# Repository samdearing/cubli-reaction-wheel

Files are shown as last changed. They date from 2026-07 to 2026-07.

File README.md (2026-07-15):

# Cubli — a 3-axis reaction-wheel balancing cube

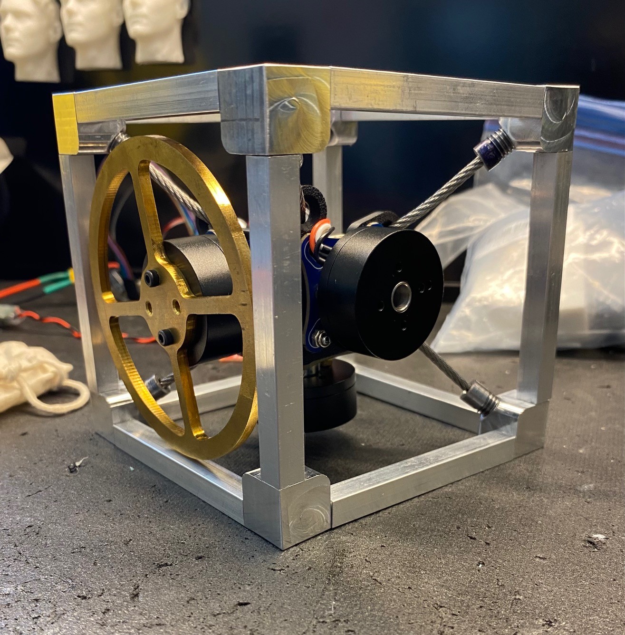
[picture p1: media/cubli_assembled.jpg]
Cubli reaction-wheel cube — first trial assembly


*First trial fit-up — dry-assembled to check clearances and see how the parts come together.
Not the finished build; frame tensioning, wiring, and final balancing are still in progress.*

A cube that balances on its corner using three orthogonal reaction wheels. Built as
phase one of a two-project arc: the ADCS stack developed here — IMU drivers, quaternion
attitude estimation, nested control loops, BLDC torque control — ports directly to an
active thrust-vector-controlled model rocket.

**Status:** prototype assembled; single-axis controller validated in simulation; **motor
bring-up complete** — one axis spinning under SimpleFOC with the encoder confirming
commanded velocity. Closed-loop edge balance is the next milestone.

---

## Why this project

Reaction-wheel attitude control is the same problem a CubeSat solves in orbit, reduced to
something you can drop on a desk. The wheel saturation, the momentum budget, the sensor
fusion, the torque-vs-momentum trade — all of it is spacecraft ADCS with gravity added as a
disturbance you can't turn off.

I built it to *understand* those things, not to reproduce a demo. Where a decision could
have been hand-waved, the reasoning is written down.

---

## The engineering, in three decisions

**The wheel is torque-limited, not momentum-limited — so bigger isn't better.**
The obvious instinct is to add wheel inertia for more authority. It's wrong. Extra rim mass
raises the gravity torque the wheel has to fight (`mgl`) faster than it raises the momentum
ceiling, and the recovery envelope is bounded by the motor's 0.087 N·m peak, not by stored
momentum. Simulation puts peak wheel speed at 56 % of the flat-torque knee during a worst-case
catch — enormous saturation margin, which is the signature of a torque-bound system. The
inertia target sits at **8.00e-5 kg·m² reflected**: the broad envelope optimum is ~7.5e-5, and
8e-5 is *also* the floor for a multi-swing pump-up hop, so one wheel design serves all three
phases instead of two. → [`docs/HARDWARE.md` §8](docs/HARDWARE.md)

**A sensor's I2C address propagated into the motor wiring harness.**
The AS5600 encoder has a hardwired address of `0x36` and no address pins — so three of them
cannot share a bus. That forces all three of the Teensy 4.1's native I2C peripherals into
service, which claims pins 24/25 for `Wire2`. Those pins happen to be FlexPWM1's sm2-X and
sm3-X outputs. FlexPWM1's usable PWM pool collapses to `{0, 1, 7, 8}`, FlexPWM3 only exposes
one submodule and can't drive a motor at all, and the whole motor pin allocation becomes
*forced* rather than chosen — including one unavoidable stray wire in the M3 harness bundle.
Traceable end to end from an encoder datasheet to a connector. → [`docs/HARDWARE.md` §11.3](docs/HARDWARE.md)

**The frame is a tensegrity, and seven stays is not a guess.**
The motor hub is a free rigid body — 6 DOF. Six cable stays can *locate* it but leave no state
of self-stress, so they'd only go taut under external load: useless as a preloaded mount. The
seventh adds exactly one self-stress state, and that self-stress *is* the preload (Maxwell:
members − 6 = self-stresses − mechanisms). The count is necessary but not sufficient — the
stays must also be arranged off the hub's center, or they lock the translations and leave it
free to spin. → [`docs/FRAME_BUILD_GUIDE.md` §2](docs/FRAME_BUILD_GUIDE.md)

---

## Architecture

Three nested loops:

| Loop | Runs at | Does |
|---|---|---|
| **Attitude** (outer) | 1 kHz | Estimated quaternion → commanded body-axis torques. PD + desaturation for single-axis; LQR for 3-axis. |
| **Allocation** (middle) | 1 kHz | Body-axis torques → per-wheel torques. Trivial for perfectly orthogonal wheels; not for real ones. |
| **Torque** (inner) | SimpleFOC | Per-motor voltage-mode torque with *estimated* current. |

**State estimation:** Madgwick → EKF. Madgwick first, deliberately, so the EKF is understood as
an answer to Madgwick's specific failures rather than adopted as a black box.

**Honest limitation:** the SimpleFOC Mini has no current-sense shunts, so the "current limit" is
enforced against an estimate derived from phase resistance — and copper resistance rises ~0.4 %/°C,
so a hot winding draws more than the estimate believes. A flight reaction-wheel driver carries a
true closed current loop for exactly this reason. Fine for low-duty balancing bursts; documented
rather than papered over.

---

## Hardware

| | |
|---|---|
| MCU | Teensy 4.1 (i.MX RT1062, 600 MHz M7 + FPU) — chosen for its **three native I2C buses** |
| Motors | QiuLovesYT 2804 BLDC ×3 — 220 KV, Kt = 0.0434 N·m/A, 7 pole pairs |
| Drivers | SimpleFOC Mini ×3 (DRV8313) — no current sense |
| Encoders | AS5600 ×3 — 12-bit magnetic, fixed 0x36 |
| IMU | SparkFun ISM330DHCX — raw 6-axis; fusion written from scratch |
| Wheels | CNC C360 brass, spoked, 87 mm OD, 65 g, 8.00e-5 kg·m² reflected |
| Frame | Pre-tensioned aluminum space-frame — 12-tube cage, machined hub, 7 cable stays |
| Power | 4S 650 mAh LiPo, star-ground distribution, 7.5 A fuse, XT30 loop key |

Full spec, wiring, pin map and limits: [`docs/HARDWARE.md`](docs/HARDWARE.md) — the single
source of truth.

---

## Simulation

Every design decision is traced through the sim before anything is cut or flashed.
*Tune in sim, then port* is the workflow, not a slogan.

```
sim/
  params.py       mass properties, motor constants, geometry
  plant.py        1-DOF rigid body + reaction wheel
  motor.py        torque envelope, saturation, back-EMF taper
  controller.py   PD + wheel desaturation
  run.py          disturbance-rejection cases, plots
```

**Validated result:** catches a 3° release + 1.0 rad/s shove down to 0.13° final tilt.
Max recoverable disturbance ≈ 1.6 rad/s (~93 °/s). Balance holds with stock gains across
±30 % on mass and inertia — the design is not gain-fragile.

Locked gains: `Kp 1.40, Kd 0.080, Kw +1e-4`. The sign on `Kw` is load-bearing — flipping it
places a right-half-plane pole and the wheel desaturates *into* the fall.

---

## Roadmap

- [x] Wheel inertia sized, balance confirmed in CAD, sim-validated
- [x] Battery + CM ballast plan closed
- [x] Electrical pin map derived and locked
- [ ] **Phase 1** — single-axis edge balance → *video of the cube balancing on an edge*
- [ ] **Phase 2** — 3-axis corner balance under LQR → *video with disturbance rejection*
- [ ] **Phase 3** — multi-swing pump-up onto a corner → *video of the hop*

---

## Repo layout

```
docs/     HARDWARE.md (source of truth) · FRAME_BUILD_GUIDE.md
          CUBLI_BUILD_CONSIDERATIONS.md · cubli_wiring_reference.html (harness ICD)
sim/      Python plant model, controller, disturbance studies
firmware/ Teensy 4.1 / SimpleFOC — bring-up + IMU sketches
cad/      SolidWorks — frame, hub, wheel, assemblies
```

---

Sam Dearing · B.S. Aerospace Engineering (astronautics), Arizona State University

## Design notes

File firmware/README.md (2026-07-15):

# Cubli — Firmware

Teensy 4.1 + SimpleFOC + AS5600. Arduino IDE 2.x.

## ⚠ REQUIRED: SimpleFOC library version 2.3.5

**Do not use SimpleFOC 2.4.0.** Its Teensy-4 driver is broken: `driver.init()` reports success
and configures the FlexPWM timers, but **no PWM ever reaches the pins** — 0 V output, motor dead,
no error. Diagnosed 2026-07-14 on this exact hardware by measuring: raw `analogWrite` on pins
4/5/6 worked perfectly, yet SimpleFOC 2.4.0 produced nothing. **2.3.5 fixes it instantly.**

Install: Arduino IDE → Library Manager → *Simple FOC* → version dropdown → **2.3.5**.

Center-aligned 3PWM is **not** used — it only matters for low-side current sensing, which the
SimpleFOC Mini doesn't have. Plain fast-pwm (the 2.3.5 default) is correct for voltage-mode
torque control. No `build_opt.h` flags, no library edits.

## Sketches

| Sketch | Purpose |
|---|---|
| **`m1_bringup/`** | The real bench tool. Serial-driven: I2C scan, encoder stream, open-loop M1 spin with encoder feedback, VBAT read, per-command enable/disable, safety timeouts. M2/M3 held disabled at the driver. **Start here.** |
| `m1_minimal/` | Barest SimpleFOC open-loop spin — no encoder, no serial. Used to isolate library vs sketch during debugging. |
| `diag_debug/` | SimpleFOC with `SimpleFOCDebug::enable()` — prints the library's PWM config decisions. The sketch that exposed the 2.4.0 bug. |
| `pwm_raw_test/` | Raw `analogWrite` on 4/5/6, no SimpleFOC. Proves the Teensy PWM hardware independent of the library. |
| `analogwrite_spin/` | Hand-rolled 3-phase sine open-loop spinner, no SimpleFOC. Proves the motor+driver turn independent of the library. |

The four small sketches are debugging artifacts kept deliberately — they're the isolation ladder
that located the 2.4.0 regression, and they'll re-diagnose any future "motor won't spin" problem.

## Pin map (Rev C — see `docs/HARDWARE.md` §11)

| Motor | IN1 | IN2 | IN3 | EN | Encoder bus |
|---|---|---|---|---|---|
| M1 | 4 | 5 | 6 | 3 | `Wire` (18/19) |
| M2 | 22 | 23 | 2 | 21 | `Wire1` (17/16) |
| M3 | 8 | 7 | 1 | 9 | `Wire2` (25/24) |

## Open-loop safety

`voltage_limit` is hard-capped at **3.0 V** in the bring-up sketch. Open loop has no back-EMF at
standstill and the Mini has no current shunts, so `I = U / Rs = U / 2.55 Ω`. The closed-loop
14.5 V would draw 5.7 A into a 2 A motor. Do not raise the open-loop cap. It returns to 14.5 V
only after `initFOC()` succeeds and the loop is closed.

## Status

- [x] I2C scan, encoder hand-turn, phase/continuity checks — all pass
- [x] M1 open-loop spin, encoder tracks commanded velocity (2026-07-14)
- [ ] `initFOC()` sensor alignment + closed-loop torque (resolves the open-loop sign flip)
- [ ] VBAT sense divider — **not yet built** (pin 41 currently floats; the ~6 V it reads is noise)

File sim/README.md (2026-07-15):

Python plant model, controller and disturbance studies.
Drop params.py / plant.py / motor.py / controller.py / run.py here.

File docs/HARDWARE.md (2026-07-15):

# Cubli — Hardware Specification (as purchased)

> **Source of truth.** This sheet reflects the parts actually bought and supersedes the
> hardware called out in the original project brief. Where it differs from the brief,
> *this document wins.* Substitutions vs. the brief are noted in the changelog at the bottom.
>
> **Rev C — 2026-07-14.** Electrical wiring, the Teensy pin map, VBAT sense, the BEC, and the
> connector ICD are now **locked in §11**. They previously lived only in conversation memory.

---

## 1. Microcontroller

| | |
|---|---|
| Board | **Teensy 4.1** |
| MCU | i.MX RT1062, 600 MHz Cortex-M7 + hardware FPU |
| Logic level | 3.3 V |
| I2C buses (exposed) | **3** — `Wire` (SDA 18 / SCL 19), `Wire1` (SDA 17 / SCL 16), `Wire2` (SDA 25 / SCL 24) |
| Power (bench) | **USB** (5 V → onboard 3.3 V regulator) |
| Power (untethered) | 3 A BEC → `VIN`, **after** the VUSB↔VIN pad cut — see §11.7 |

The three independent I2C buses are load-bearing for this design — see §6.

> `Wire2` (SDA 25 / SCL 24) has **no alternate pins** on this MCU. Those two pins are also
> FlexPWM1's sm2-X and sm3-X outputs, so committing to a third I2C bus removes them from the
> PWM pool. That is what forces the motor pin allocation in §11.3 — the constraint is real and
> traceable, not a layout accident.

---

## 2. Motors — QiuLovesYT 2804 BLDC (×3)

Gimbal-style outrunner, hollow shaft. *Replaces the GBM2804 / MN3110 in the brief.*

| Parameter | Value | Notes |
|---|---|---|
| KV | 220 RPM/V | True low-KV → high torque/amp, ideal for reaction-wheel torque control |
| Torque constant Kt | 0.0434 N·m/A | = Ke; self-consistent with KV (9.549 / 220) |
| Back-EMF constant Ke | 0.0434 V·s/rad | |
| Pole pairs | **7** (12N14P) | → `BLDCMotor(7)` in SimpleFOC |
| Phase resistance Rs | 2.55 Ω | line-to-line winding R = 5.1 Ω |
| Phase inductance Ls | 0.86 mH | electrical time constant τ = L/R ≈ **337 µs** — sets the PWM frequency floor (§11.4) |
| Rated current | 0.5 A | continuous |
| **Max current** | **2.0 A** | hard limit → `current_limit = 2.0` (enforced by *estimate* — see §3) |
| Continuous torque | ≈ 0.022 N·m | Kt × 0.5 A |
| **Peak torque** | ≈ 0.087 N·m | Kt × 2.0 A |
| Rotor inertia | 3.7e-6 kg·m² | add to flywheel inertia for the precise plant model |
| No-load speed | 2600 RPM @ 12 V | ≈ 272 rad/s @ 12 V. Operating envelope set by `voltage_limit` — see below |
| Magnetic flux | 0.0035 Wb | |
| Operating voltage | 7.4–16 V (rated 12 V) | **20 V absolute max** — see §7 |
| Phase connector | MX1.25, 3-pin | |
| Shaft | 8 mm OD, 6.5 mm bore, hollow 5.4–6.5 mm | pre-installed radial magnet ring for the encoder |
| Body size | 34.5 × 15 mm (19.5 mm tall w/ magnet ring) | |

**Speed/torque envelope at `voltage_limit = 14.5 V` (the numbers that matter):**

- **Flat-torque knee ≈ 217 rad/s** — `(V_lim − I_lim·Rs)/Ke`. Below this the *current* limit
  binds and the full 0.087 N·m is available. **This is the speed to use for momentum budgets.**
- **Zero-torque asymptote ≈ 334 rad/s** — `V_lim/Ke`. Between 217 and 334 the available motoring
  torque tapers linearly to zero; the wheel can coast near 334 but cannot accelerate there under
  load. Treat it as a wall, not an operating point. (Braking torque does *not* taper — see §9.)

**Thermal caveat:** peak (2 A) torque is *not* sustainable continuously — rated current is only
0.5 A. Balancing is low-duty on torque (wheel idles near zero with bursts), so RMS current stays
well under 2 A in practice.

> ### ⚠ OPEN-LOOP VOLTAGE LIMIT — the number that kills motors
> `voltage_limit = 14.5 V` is a **closed-loop** number. It is safe only because back-EMF opposes
> the applied voltage once the rotor is turning and the current *estimate* throttles the command.
>
> **In open loop there is no back-EMF at standstill and no current shunt to catch it.** The
> winding current is simply `I = U / Rs`:
>
> | Applied U | Current into 2.55 Ω | Verdict |
> |---|---|---|
> | 14.5 V | **5.7 A** | 2.85× the 2.0 A max — destroys the winding |
> | 5.1 V | 2.0 A | exactly at the hard limit |
> | **3.0 V** | **1.18 A** | **use this for any open-loop bring-up** |
>
> Invert it: `U_max = I_max · Rs = 2.0 × 2.55 = 5.1 V`. **Any open-loop test sets
> `motor.voltage_limit` to 2–3 V.** It returns to 14.5 only after `initFOC()` succeeds.

---

## 3. Motor drivers — SimpleFOC Mini (×3)

Bundled with the motor kit. DRV8313-based.

| Parameter | Value | Notes |
|---|---|---|
| Driver IC | DRV8313 (3 × half-bridge) | |
| Input voltage (VM) | 8–30 V | **8 V floor is the binding constraint** |
| Max current | 2.5 A / phase | motor's 2 A is the tighter limit |
| **Current sensing** | **NONE** | the board has no shunts — see note below ⚠ |
| Onboard 3.3 V LDO | 10 mA only | **cannot power the Teensy** — logic runs on USB / BEC |
| Control pins | IN1, IN2, IN3, EN (3.3 V logic) | + common GND (mandatory, see §7 and §11.1) |
| Size | ~26 × 21 mm | |

> ⚠ **No current sense → no closed current loop.** The "inner torque loop" on this board is
> SimpleFOC **voltage-mode torque control with *estimated* current**: the library uses
> `phase_resistance` + `KV_rating` to estimate the current and enforce `current_limit`.
> Consequences: (1) torque accuracy and the 2 A limit ride on the Rs estimate — copper rises
> ~0.4 %/°C, so a hot winding draws more than the estimate believes; (2) this is fine for our
> low-duty balancing bursts, but it is an *estimated* limit, not a measured one. Flight
> reaction-wheel electronics carry true current loops for exactly this reason — note the
> difference in the portfolio writeup. True FOC current control would require a driver with
> shunts (e.g. SimpleFOC Shield v2); not needed for this project.

---

## 4. Encoders — AS5600 magnetic (×3)

Bundled and pre-mounted on each motor's hollow-shaft magnet; reads to the Teensy over I2C.

| Parameter | Value | Notes |
|---|---|---|
| Type | 12-bit magnetic rotary encoder, I2C | absolute single-turn |
| **I2C address** | **0x36 — FIXED** | standard AS5600 has *no* address pins ⚠ |
| Supply | 3.3 V | onboard pull-ups present |

> ⚠ **The AS5600 address is hardwired to 0x36 and cannot be changed.** Three of them therefore
> **cannot share one I2C bus.** The solution is one encoder per Teensy bus (see §6). *(Only the
> AS5600**L** variant has a programmable address — confirm which you have.)*

> **Phase-2 timing note:** `Wire` reads are blocking; three sequential AS5600 angle reads at
> 400 kHz cost ~300 µs of the 1000 µs loop tick. Fine for one encoder (Phase 1); at three,
> stagger the reads, run encoders below the control rate, or go non-blocking.

---

## 5. IMU — SparkFun Qwiic ISM330DHCX (×1)

ST 6-axis (raw accel + gyro, no on-chip fusion). *Replaces the ICM-42688-P in the brief.*

| Parameter | Value | Notes |
|---|---|---|
| Interface | I2C / Qwiic | also 0.1" pins; 3.3 V (direct to Teensy, no level shift) |
| I2C address | ~0x6B | ADR jumper open; confirm with a bus scan |
| Accel full-scale | ±2 / ±4 / ±8 / ±16 g | likely **±4 g** (tilt resolution + impact margin) |
| Gyro full-scale | ±125 … ±4000 dps | **±500–1000 dps** for balance; widen for hop-up |
| Features | FIFO, interrupts, ML core/FSM | ML core unused — fusion is written from scratch |

---

## 6. I2C bus map

Because all three AS5600s answer to **0x36**, each gets its own bus. The IMU (0x6B) is free to
share, since its address differs.

| Bus | Pins (SDA/SCL) | Devices | Phase |
|---|---|---|---|
| `Wire`  | 18 / 19 | AS5600 #1 (0x36) **+** ISM330DHCX (0x6B) | Phase 1 + |
| `Wire1` | 17 / 16 | AS5600 #2 (0x36) | Phase 2 |
| `Wire2` | 25 / 24 | AS5600 #3 (0x36) | Phase 2 |

No I2C multiplexer needed — the Teensy's three native buses cover all three encoders. Internal
pull-ups on the T4.1 are weak, but every device board here ships its own pull-ups, so a single
device (or the IMU+encoder pair) per bus is fine.

> **The three-bus choice has a downstream cost.** `Wire2` claims pins 24/25, which are also
> FlexPWM1's sm2-X and sm3-X. That reduces FlexPWM1's usable PWM outputs to `{0, 1, 7, 8}` and
> forces one stray wire in the M3 harness bundle (§11.3). Traceable all the way back to the
> AS5600's fixed 0x36 address. Worth stating plainly in the portfolio writeup: *a sensor's I2C
> addressing scheme propagated into the motor wiring harness.*

---

## 7. Power architecture & SimpleFOC limits

```
  USB ──► Teensy 4.1 (+ IMU, + AS5600 logic via Teensy 3.3 V)
                │
                └── PWM ×3 + EN ──► SimpleFOC Mini ×3 ──► motor phases (UVW)
  4S LiPo ──────────────────────────► VM (motor supply only)
                                       │
        COMMON GROUND  ◄── battery GND ─┴─ Teensy GND  (MANDATORY)
```

Full distribution topology, connector ICD and pin map: **§11**.

- **4S LiPo** (650 mAh — locked, see §10): 14.8 V nom / 16.8 V full / ~12 V cutoff. Stays clear of
  the driver's 8 V floor across the whole discharge, and matches the TVC-rocket bus.
- **Voltage tension:** 4S full charge (16.8 V) sits just above the motor's 16 V rated operating
  ceiling (under the 20 V abs max). Resolved in software: under voltage-mode torque control the
  commanded phase voltage never exceeds `voltage_limit`, so the full bus is never applied to the
  windings. **Set `voltage_limit ≈ 14.5 V`** (below the 16.8 V full-charge bus; gives the 217 rad/s
  flat-torque region / 334 rad/s asymptote of §2) **and `current_limit = 2.0 A`** (estimated — §3).
  The envelope sags as the pack discharges, so run recovery/shove tests on a reasonably charged pack.
- **Common ground is mandatory** — logic (USB) and motor power (LiPo) are separate domains; the
  PWM/EN signals are ground-referenced, so the grounds must be tied, **at the star node** (§11.5).
- **Phase 3 watch item:** hard braking during the hop-up regenerates energy onto the bus and can
  push it toward the 20 V abs max — brake chopper before Phase 3 (see §9).

### SimpleFOC config (per motor — closed loop)

```cpp
BLDCMotor      motor  = BLDCMotor(7);          // 7 pole pairs
motor.phase_resistance = 2.55;                 // ohms  (Rs)   -> enables current ESTIMATION
motor.phase_inductance = 0.00086;              // henries (0.86 mH)
motor.KV_rating        = 220;                  // RPM/V        -> enables back-EMF estimation
motor.torque_controller = TorqueControlType::voltage;  // the only mode this driver supports
motor.voltage_limit    = 14.5;                 // V — CLOSED LOOP ONLY. Open loop: 2-3 V (§2)
motor.current_limit    = 2.0;                  // A — motor hard max (estimated, no shunts)
// AS5600 sensor on its own I2C bus (addr 0x36); MagneticSensorI2C per motor
```

---

## 8. Balance wheel — machined C360 brass, spoked (×3)

*Supersedes the earlier printed-PETG / 75 mm / 5.0e-5 plan. The wheel is now CNC-machined in
brass: the larger OD reachable in metal moved the recovery-envelope optimum up, and the target is
set at the multi-swing-pump-up floor so one wheel can serve Phase 1–3 (see §9).*

| | |
|---|---|
| Type | **CNC-machined C360 free-machining brass, spoked rim-loaded disc (×3)** |
| Material | **C360** (machinability 100). *Not C260* — that's a cold-forming alloy (machinability ~30, gummy); identical density (~8500 kg/m³) so it'd hit the inertia but machines poorly |
| Stock | **1/8″ (3.175 mm) C360 plate**, full thickness retained on rim / spokes / hub |
| OD | **87 mm** (CAD-confirmed: ~2 mm inter-wheel gap at the shared corner, clears the ground-contact corner/edges) |
| Geometry | **Spoked:** rim **5.9 mm** wide at full 1/8″; **4 narrow (~4 mm) full-depth spokes**; **through-pockets** between spokes; **4 mm fillets** at spoke↔rim and spoke↔hub junctions; hub Ø set by the 2804 bell bolt pattern |
| As-designed mass | **65.2 g each** (SolidWorks; from a ~160 g solid 1/8″ blank → ~95 g removed) |
| **Spin-axis inertia** | **disk 7.63e-5 kg·m² (Lzz 76,304 g·mm²) → 8.00e-5 kg·m² reflected** (incl. rotor 3.7e-6). Hit dead-on in CAD — no trim, one-and-done |
| Mount / register | **Center pilot** locates the wheel: ~4–5 mm spigot, ~0.03 mm slip-fit into the bell's 6.5 mm **rotating** bore (machine to fit), seats on the bell **face** (must not bottom). **3× M2.5** clearance holes at **2.8–2.9 mm** — bolts clamp, pilot centers; edge distance ≥1.5× hole Ø. **No trim screws** — the tight build can't take rim protrusions, so inertia is hit in CAD instead |
| Balance | **Confirmed in SolidWorks:** CM at X = Y = 0, all products of inertia zero, Z a clean principal axis. Cut the pilot and rim in one setup to hold concentricity (runout = wobble = imbalance) |

**Verified (2026-06-09, mass estimates m ≈ 0.70 kg / I_bar ≈ 5.0e-3):** sim-confirmed balanced at
8.0e-5 — `run.py` catches a 3° release + 1.0 rad/s shove down to 0.13° final tilt, peak wheel speed
121 rad/s = **56 % of the 217 rad/s flat-torque region**. Large saturation margin → the system is
torque-limited, not momentum-limited, as expected. Max recoverable shove ≈ **1.6 rad/s (~93 °/s)**;
balance holds with stock gains across m 0.6–0.9 kg, I_bar 4–6e-3.

**Why ~8e-5 (not the old 5.0e-5, not more):** at 87 mm OD the recovery-envelope optimum sits on a
broad plateau ~7.5e-5; the target is nudged to **8e-5 because that is also the floor for a
multi-swing pump-up hop**, so the *same* wheel covers Phase 1–3 with no swap. The balance cost of
8e-5 vs the pure 7.5e-5 optimum is ~1–1.5 % of envelope — inside the rotor-estimate and
mass-tensor uncertainty. Past ~8e-5, extra inertia is flat (you're already past the saturation
knee) while the added mass *shrinks* the torque-limited envelope — balancing is torque-bound, not
momentum-bound (τ ceiling 0.087 N·m is fixed by the motor, §2). Bigger OD is the efficient lever:
I ∝ m·r², so 87 mm hits 8e-5 at lower rim mass.

**Why spoked + full thickness (the machining principle):** out-of-plane stiffness scales as
**thickness³**, so *never* thin a feature to save mass — drop a spoke 1/8″→2 mm and you keep 63 %
of the mass but only 25 % of the stiffness. Minimize mass **in-plane** (through-pockets between
narrow, full-depth spokes), keep rim/spokes/hub at full 1/8″. Strength is a non-issue (0.087 N·m
peak → trivial stress); the real constraint is **trueness** — a flat, concentric wheel that doesn't
wobble (which also keeps the IMU clean) and whose first resonance sits well above the ~50 Hz top
spin rate.

**Tooling (C360):** 2-flute, **uncoated**, carbide (or HSS — C360 is soft), **low/neutral rake,
lower helix** — avoid "for-aluminium" high-helix/high-rake mills, which *grab* in brass. A 1/4″ mill
(leaves a 1/8″-radius inside corner) cuts the whole wheel if fillets are ≥1/8″ R and pockets stay
>~6.5 mm. Rough the pockets while the blank is rigid; profile the thin rim last; back
through-pockets with a sacrificial plate.

**Phase 3:** plan is a **multi-swing pump-up** using this same ~8e-5 wheel (no second wheel). The
pump-up momentum budget must use the *tapered* τ(ω) envelope of §2 — spin-up slows past 217 rad/s
and the last ~30 rad/s before 334 is effectively unreachable under load. A dedicated single-dump
hop wheel (~16e-5, brass) remains the fallback — the **hub is designed modular to accept a heavier
rim** either way.

---

## 9. Still open (not yet locked)

- ~~PWM pin map / star-ground topology~~ → **✅ LOCKED, §11.2 / §11.5**
- ~~VBAT sense divider~~ → **✅ LOCKED, §11.6**
- ~~BEC + VUSB↔VIN cut sequencing~~ → **✅ LOCKED (deferred to post-Phase-1), §11.7**
- ~~Battery capacity~~ → **✅ locked: 4S 650 mAh** (§10)
- ~~Wheel OD / inertia~~ → **✅ 87 mm, 8.00e-5 reflected, balance confirmed** (§8)
- ~~`voltage_limit`~~ → **✅ 14.5 V closed-loop; 2–3 V open-loop** (§2, §7)

**Genuinely still open:**

- **Ballast final mass & position** — ~45–50 g brass at the far corner closes the CM (working
  numbers in §10); finalize against the *full* SolidWorks assembly and the weighed pack.
- **Full-assembly mass tensor** — the 418 g / 4,810 g·mm CM figures in §10 predate the
  aluminum-frame lock. Re-run against the as-built space-frame, then feed `params.py`.
- **IMU accel/gyro full-scale** selection (balance range now; **widen the gyro for the Phase-3
  hop** — the pump-up still slews fast).
- **Phase 3 regen-overvoltage mitigation** — brake chopper (power resistor + MOSFET on bus
  overvoltage); required for *any* hop-up, pump-up included. **Energy sized:**
  E = ½·I_w·ω² ≈ **1.9 J per wheel** braking from the 217 rad/s knee (worst case ~4.2 J from a
  334 rad/s coast — don't plan to be there). Single-event energy is trivial for any chassis-mount
  power resistor; the design driver is the *dump rate* during a hard brake (sets resistor wattage +
  MOSFET trip point). Size when Phase 3 starts. Trip signal comes from the §11.6 VBAT sense.

---

## 10. Frame & battery

- **Frame:** pre-tensioned aluminum space-frame — a 12-tube 6063 cage + 8 machined corner blocks, a
  central machined-aluminum motor hub, suspended by **7 pre-tensioned 1/8″ stranded-cable stays**
  (no rigid strut; 7 = 6 to constrain + 1 to prestress). **Full spec lives in
  `FRAME_BUILD_GUIDE.md`** (the frame source of truth). Cube edge `E` is **open pending the CAD
  inter-wheel / stay-clearance check**. Supersedes the old 3D-printed PETG ~100 mm cube.
- **Battery: 4S LiPo 650 mAh — LOCKED.** Typical pack: ~60 × 31 × 21 mm, **70–85 g**
  (brand-dependent — **weigh the actual pack** and feed the number to the CM analysis and
  `params.py`). Peak draw 3 × 2 A = 6 A ≈ **9 C** — any ≥25 C pack loafs; capacity gives well over
  an hour of balancing per charge at typical duty.
- **Battery placement + brass ballast (the CM plan).** Placement is a controls decision, not
  packaging: as-modeled (no battery) the assembly is **418 g with the CM at (+11.5, +11.6, +11.5)
  mm** — ~20 mm up the body diagonal toward the three-wheel corner — so **4,810 g·mm of
  countermoment per axis** is needed. A 650 pack (~75 g) at a practical interior placement (~38 mm
  per axis toward the (−,−,−) corner) supplies only **~2,850 g·mm (≈ 59 %)**. Close the remainder
  with **~45–50 g of brass ballast** packed deeper into the far corner (~42 mm per axis) — the
  wheel-blank offcuts are free stock. Net: battery + ballast ≈ **122 g** does the job of the old
  150 g / 1500 mAh plan at *lower* total mass, and dense brass is more precisely placeable than a
  battery brick. Keep both near the [1,1,1] diagonal to preserve Ixx ≈ Iyy ≈ Izz and the diagonal
  principal axis. **The 418 g / 4,810 g·mm figures predate the aluminum-frame lock — re-run the
  full mass tensor against the as-built space-frame before committing ballast.**

---

## 11. Electrical wiring, pin map & harness ICD — **LOCKED (Rev C)**

The pin map below is a decision, not a proposal. It is a hard dependency for the firmware skeleton
and for the harness build. Drawing: `cubli_wiring_reference.html`.

### 11.1 SimpleFOC Mini — what every pin connects to

| Mini pin | Connects to | Domain |
|---|---|---|
| `VM`, `GND` (power header) | Distribution board → 4S bus | Motor power (14.8 V nom) |
| `A`, `B`, `C` | Motor phases U / V / W (MX1.25, 3-pin) | Motor power |
| `IN1`, `IN2`, `IN3` | Three Teensy FlexPWM pins (§11.2) | 3.3 V logic |
| `EN` | One Teensy digital pin, per motor | 3.3 V logic |
| `GND` (logic header) | Teensy GND — **routed inside the signal bundle** | Signal reference |
| `3V3` out | **Nothing. Leave floating.** | — |

**Two failure modes to design against.**

1. **The logic-side `GND` is not "just another ground."** It is the reference the DRV8313 compares
   the incoming PWM/EN levels against. It rides in the JST GH signal bundle with the four signals it
   references — *not* bundled with the motor return. A signal ground sharing an impedance path with
   6 A of switched phase current is the textbook common-impedance coupling failure, and it presents
   as I2C corruption and phantom controller instability, not as an obvious wiring fault.
2. **The Mini's `3V3` out is a 10 mA LDO** (§3). Tying it to the Teensy's 3.3 V rail parallels two
   regulators with no droop sharing. Leave the pin open.

**Phase order (`A`/`B`/`C` → U/V/W):** arbitrary at build time; the pairing sets the sign of
rotation, and `initFOC()` discovers the sensor direction and electrical zero at startup. What
matters is that the mapping is *recorded per axis* and identical across rebuilds (§11.8).

### 11.2 Teensy 4.1 pin map — LOCKED

| Motor | IN1 | IN2 | IN3 | EN | FlexPWM module · channel | Harness bundle | Encoder bus |
|---|---|---|---|---|---|---|---|
| **M1** (Phase 1) | **4** | **5** | **6** | **3** | PWM2 · sm0A / sm1A / sm2A | **pins 3–6, contiguous** | `Wire` (18/19) |
| **M2** | **22** | **23** | **2** | **21** | PWM4 · sm0A / sm1A / sm2A | 21–23 + one stray at 2 | `Wire1` (17/16) |
| **M3** | **8** | **7** | **1** | **9** | PWM1 · sm3A / sm3B / sm0X | 7–9 + one stray at 1 | `Wire2` (25/24) |

| Other signal | Pin | Notes |
|---|---|---|
| VBAT sense | **41** (`A17`) | 68 k : 10 k divider + 100 nF — §11.6 |

**Reserved, do not reallocate:** 16, 17, 18, 19, 24, 25 (the three I2C buses).
**Never use for a phase:** 10–15, 18, 19 — **QuadTimer**, not FlexPWM. SimpleFOC's Teensy-4 3PWM
wants FlexPWM pins; keep every phase on a FlexPWM channel (see §11.4).

### 11.3 Why these pins — the derivation

All three phases of one motor must sit on **one FlexPWM module** so they share a carrier. Phases on
different modules run on free-running, mutually unsynchronized counters; the inverter legs then
switch incoherently and the applied voltage vector is not what the modulator thinks it is.

**Accessible FlexPWM outputs on the Teensy 4.1** (pins 42–47, 51, 54 are SD-card / bottom pads and
are not usable):

| Module | sm0 | sm1 | sm2 | sm3 |
|---|---|---|---|---|
| **FlexPWM1** | X = 1 | X = 0 | X = 24 ❌ | A = 8, B = 7, X = 25 ❌ |
| **FlexPWM2** | A = 4, B = 33 | A = 5 | A = 6, B = 9 | A = 36, B = 37 |
| **FlexPWM3** | — | A = 29, B = 28 | — | — |
| **FlexPWM4** | A = 22 | A = 23 | A = 2, B = 3 | — |

❌ = consumed by `Wire2`, which has no alternate pins.

- **`Wire2` costs us FlexPWM1.** Its usable outputs collapse to `{0, 1, 7, 8}` — two adjacent pairs
  with a six-pin gap. **M3's stray wire is the price of the third I2C bus,** which is itself the
  price of the AS5600's fixed 0x36 address (§4).
- **FlexPWM3 cannot drive a motor.** Only submodule 1 is brought out (28/29). One submodule cannot
  host three independently-modulated phases.
- **FlexPWM4's third submodule surfaces only at pin 2 or 3**, on the opposite header row from
  22/23. M2's stray is therefore also forced.
- **No two motors may share a FlexPWM module.** FlexPWM2 has enough outputs for two motors, but only
  by sharing a submodule between two `BLDCDriver3PWM` instances — two driver objects writing the
  same submodule's counter registers. Untested and unnecessary.

**Therefore the allocation is forced:** PWM2 → M1, PWM4 → M2, PWM1 → M3. Two stray wires across the
whole harness is the floor, not a compromise.

**EN pins** need no timer, only a digital output, so each sits adjacent to its motor's phase group:
`3` for M1 (FlexPWM4 sm2-B, unused as a timer), `21` for M2 (plain GPIO), `9` for M3 (FlexPWM2 sm2-B,
unused as a timer). Driving a pin as GPIO re-muxes only that pin and does not disturb the submodule
counter its sibling channel uses.

**Why three separate EN lines** — a bring-up safety feature, not a convenience. It lets you
hardware-isolate two motors *at the driver* while characterizing the third. "Commanded to zero in
firmware" is not isolation; a bad `initFOC()` or a sign error still energizes the phases.

### 11.4 Firmware config

> ### ⚠ PIN THE LIBRARY: SimpleFOC **2.3.5**. Do NOT use 2.4.0.
> **SimpleFOC 2.4.0's Teensy-4 driver is broken:** `driver.init()` reports success and configures
> the FlexPWM (both fast-pwm and center-aligned), but **no PWM reaches the pins — 0 V output, motor
> dead.** Verified 2026-07-14 on this exact hardware: raw `analogWrite` on pins 4/5/6 worked, yet
> SimpleFOC 2.4.0 produced nothing. **Downgrading to 2.3.5 fixed it instantly** — the default
> fast-pwm 3PWM path spins the motor. This cost an afternoon; it is the first thing to check if the
> motor ever goes silent after a library update.
>
> Debugging lesson worth keeping: `driver.init()` returning `1` and printing a happy config line is
> **not** proof of output. Confirm PWM with a meter on the pins, or with `SimpleFOCDebug::enable()`.

**Center-aligned 3PWM is NOT needed for this project.** It only matters for low-side current
sensing, and the SimpleFOC Mini has no shunts (§3). Plain fast-pwm 3PWM (the 2.3.5 default) is
correct for voltage-mode torque control. No `build_opt.h`, no library edits, no compiler flags.

```cpp
#include <SimpleFOC.h>   // library version 2.3.5 (see warning above)

BLDCDriver3PWM driver1 = BLDCDriver3PWM(4, 5, 6, 3);    // M1 — FlexPWM2
BLDCDriver3PWM driver2 = BLDCDriver3PWM(22, 23, 2, 21); // M2 — FlexPWM4
BLDCDriver3PWM driver3 = BLDCDriver3PWM(8, 7, 1, 9);    // M3 — FlexPWM1

driver1.pwm_frequency        = 25000;   // set explicitly; do not rely on the default
driver1.voltage_power_supply = 14.8;    // corrected at runtime from VBAT sense (§11.6)
```

**On 25 kHz:** above audible, and short against the motor's electrical time constant
τ = L/R = 0.86 mH / 2.55 Ω ≈ **337 µs**. The current ripple over one 40 µs period is therefore small
and the voltage-mode current *estimate* (§3) stays meaningful. Justify any change against τ.

### 11.5 Power distribution & star ground

```
  USB 5 V ──► Teensy 4.1 ──► 3.3 V rail ──► IMU + 3× AS5600   (~40–60 mA of a 250 mA rail)
                  │
                  ├── 3× (IN1,IN2,IN3,EN,GND) ──► SimpleFOC Mini ×3   [JST GH 5-pin]
                  │
  4S LiPo ──► XT30 loop key ──► 7.5 A fuse ──► DISTRIBUTION BOARD
                                                 ├─ 470 µF bulk
                                                 ├─ VM fan-out ×3 ──► Mini VM   [JST XH 2-pin]
                                                 ├─ VBAT divider ──► pin 41
                                                 └─ ★ STAR GROUND NODE  ◄── Teensy GND
```

- **Common ground is tied at the star node**, not opportunistically at the nearest GND pin. Motor
  return current must never share an impedance path with a signal reference. *(Spacecraft EPS
  practice, and the reason a "works on the bench, fails assembled" bug is almost always grounding.)*
- **470 µF bulk at the distribution board**, plus local decoupling at each Mini's `VM`. The lead
  inductance between bulk cap and half-bridge is what turns a switching edge into ringing overshoot.
- **Peak draw** 3 × 2 A = 6 A ≈ 9 C. The 7.5 A fuse sits above the 6 A peak, below the harness limit.

### 11.6 VBAT sense divider

> **Status: designed, NOT YET BUILT (2026-07-14).** Pin 41 currently floats — the bring-up
> sketch's ~6 V reading is noise on an unconnected ADC input, not a battery reading. Build the
> divider before relying on any VBAT telemetry or the undervoltage cutoff.

68 kΩ from the 4S bus to a node; 10 kΩ from that node to star ground; node → **pin 41 (`A17`)**;
**100 nF across the 10 kΩ**.

| Quantity | Value |
|---|---|
| Divider ratio | 10 / (68 + 10) = **0.128** |
| Reading at 16.8 V (full pack) | **2.15 V** — inside the 0–3.3 V ADC window |
| Full-scale bus (3.3 V at the pin) | **≈ 25.7 V** |
| Thévenin source impedance | 68k ‖ 10k ≈ **8.7 kΩ** |
| Quiescent draw | 16.8 V / 78 kΩ ≈ **215 µA** (negligible vs 650 mAh) |

**The 100 nF is not optional:** 8.7 kΩ is at the edge of what the Teensy's SAR ADC wants to see. The
cap gives the sampling capacitor a local reservoir so the conversion doesn't droop.

**Three jobs — this is a telemetry channel, not a battery gauge:**

1. **Undervoltage cutoff.** Drop all three EN lines at ~12 V (3.0 V/cell).
2. **Correct `voltage_power_supply` at runtime.** Under voltage-mode torque control the commanded
   torque *is* a voltage. If the bus sags and firmware assumes 14.8 V, the applied torque quietly
   scales down and the tuning drifts with state of charge. Feed the measured bus back each loop.
3. **Phase-3 regen overvoltage detection.** Trips the brake chopper before the bus reaches the
   motor's 20 V absolute max (§9).

> **Transfers to TVC verbatim.** Bus telemetry + undervoltage lockout is the same channel a flight
> vehicle's EPS carries, for the same three reasons.

### 11.7 BEC — 3 A, untethered only. **NOT INSTALLED.**

A 3 A / 5 V step-down off the 4S bus, feeding Teensy `VIN`, so the board runs without USB. Against a
~150 mA logic load, 3 A is comfortable margin.

> ### ⚠ The VUSB↔VIN pad must be cut **before** the BEC is ever connected.
> With the pad intact, feeding 5 V into `VIN` shorts the BEC output to the PC's USB rail.
> The cut is **not practically reversible** and it changes bench behavior immediately — the Teensy
> will no longer run from USB alone.
>
> **Sequencing rule (extends §12):** the BEC is fitted and the pad is cut only *after* Phase-1
> balancing is achieved on USB. It is not part of any bench bring-up.

### 11.8 Connector ICD

| Interface | Connector | Signals | Notes |
|---|---|---|---|
| Motor phases | MX1.25, 3-pin | U / V / W | Staked with RTV at the motor junction |
| Driver VM power | JST XH, 2-pin | VM / GND | Twisted pair back to the star node |
| Driver control | JST GH, 5-pin (gold) | IN1 / IN2 / IN3 / EN / **GND** | GND travels with the signals it references |
| Encoder & IMU I2C | Qwiic / JST GH | 3V3 / GND / SDA / SCL | One bus per encoder; keep runs short |

**Color-band and label all three axis harnesses at both ends.** Three identical subsystems is a
cross-wiring trap: a swapped M2/M3 bundle presents as a controller *sign error*, which you will hunt
in software for a weekend. **M1 = red, M2 = green, M3 = blue**, banded at both connector ends.

**Mounting:** boards on short standoffs, short load path into a structural member; target first mode
≳ 100 Hz to stay above the 0–50 Hz wheel excitation band; strain-relieve at every board. The failure
mode is **connector fatigue, not structure** — the boards are too light to disturb the dynamics, but
an under-constrained mount gives intermittent I2C that looks exactly like a firmware bug.

### 11.9 Bench rules — breadboard limits

| Breadboard is fine | Point-to-point wire only |
|---|---|
| Teensy, IMU, AS5600s, all I2C | **Motor phases (U/V/W)** |
| PWM / EN signal lines | **VM rail and its return** |
| VBAT divider | Bulk + local decoupling caps |

Breadboard contacts are rated ~1 A against a 6 A peak, carry tens of milliohms of contact
resistance, and add loop inductance exactly where di/dt is highest. Everything up to a valid Madgwick
quaternion is breadboard-safe; nothing past the loop key is.

---

## 12. Bring-up order (standing procedure — not a status)

1. **Logic before motor power.** Teensy on USB only, no battery, loop key **out**. Scan all three
   I2C buses; confirm 0x36 on each and 0x6B on `Wire` before trusting any reading.
2. **Continuity check.** Every harness GND → star node (<1 Ω). Ohm out each phase bundle: no
   phase-to-phase and no phase-to-GND short. **Do this on every re-mate.** Re-seating a connector is
   exactly when a strand bridges.
3. **IMU first light.** Raw accel + gyro clean over serial; sanity-check axes, units, bias, noise.
4. **Madgwick.** Valid, stable quaternion at rest and under hand rotation.
5. **Sensor check.** AS5600 angle monotonic and wrapping cleanly when the rotor is turned by hand.
6. **Then motor power.** All EN lines LOW → insert loop key → verify VBAT sense reads within ~2 % of
   a meter on the pack.
7. **Open loop, M1 only, `voltage_limit = 2–3 V`** (§2 ⚠). M2/M3 held disabled at the driver.
8. **`initFOC()`** on M1 — sensor alignment. Only then does `voltage_limit` return to 14.5 V.

> **Step 6 is the boundary.** Everything before it is recoverable; a wiring error after it is a dead
> driver, a dead Teensy, or a LiPo event.

---

## Changelog vs. original brief

| Item | Brief said | Actually using | Why |
|---|---|---|---|
| IMU | ICM-42688-P | **SparkFun ISM330DHCX** | ICM-42688-P supply crunch; ISM is raw 6-axis (learning goal intact) |
| Motor | GBM2804 / MN3110, "low-KV 600–1200" | **QiuLovesYT 2804, 220 KV** | 220 KV is genuinely low-KV; the "600–1200" figure was backwards |
| Driver | SimpleFOC Mini (separate) | SimpleFOC Mini (**bundled** w/ motor kit) | same board, came in the kit |
| Driver torque mode | (implied closed current loop / "FOC") | **Voltage-mode torque w/ estimated current** | SimpleFOC Mini has **no current sensing**; `current_limit` is enforced by estimate (§3) |
| Encoder | (implied AS5600) | **AS5600 ×3, pre-mounted** | bundled; note the fixed-0x36 / 3-bus constraint |
| Frame | ~150 mm printed PETG cube | **Pre-tensioned aluminum space-frame** (`FRAME_BUILD_GUIDE.md`) | Machined frame for stiffness + a precision perpendicular hub (PETG drifts/creeps) |
| Flywheel | brass C360, ~80 mm × ~20 mm placeholder | **CNC C360 brass, spoked, 87 mm OD, 5.9 mm rim, 1/8″ stock, 65 g, center-pilot register** | Metal OD reachable (87 mm) moved the optimum up; one wheel now covers all phases (§8) |
| Wheel inertia | I_w 3.68e-5 / 4.05e-5 reflected | **8.00e-5 reflected** (hit dead-on in CAD, sim-confirmed) | Larger OD lifted the envelope plateau (~7.5e-5); 8e-5 = the pump-up-hop floor, so one wheel serves Phase 1–3 |
| `voltage_limit` | (open) | **14.5 V closed-loop; 2–3 V open-loop** | Closed loop: flat torque to ~217 rad/s, zero at ~334, below the 16.8 V full-charge bus. **Open loop has no back-EMF — 14.5 V would draw 5.7 A into a 2 A motor (§2 ⚠)** |
| Battery | 4S, capacity TBD (1500–2200) | **4S 650 mAh (~75 g) + ~45–50 g brass corner ballast** | CM closed at *lower* total mass than a big pack (122 g vs 150+ g); 9 C peak draw is trivial; brass is a more precise CM lever (§10) |
| M1 drive pins | (not specified) | **IN 4 / 5 / 6, EN 3** — FlexPWM2 | One FlexPWM module per motor; bundle fully contiguous |
| M2 drive pins | (not specified) | **IN 22 / 23 / 2, EN 21** — FlexPWM4 | FlexPWM4's third submodule surfaces only at pin 2/3 — the stray wire is forced |
| M3 drive pins | earlier draft: 8 / 7 / ~~29~~, EN 32 | **IN 8 / 7 / 1, EN 9** — FlexPWM1 | **Defect fix.** The draft straddled FlexPWM1 *and* FlexPWM3 — two unsynchronized carriers on one motor. `Wire2` blocks 24/25, leaving FlexPWM1 with only {0,1,7,8} |
| EN pins | earlier draft: 30 / 31 / 32 | **3 / 21 / 9** | Placed adjacent to each motor's phase group so the 5-wire bundle leaves the board from one place |
| PWM mode | (implied default) | **`SIMPLEFOC_TEENSY4_FORCE_CENTER_ALIGNED_3PWM`**, 25 kHz | SimpleFOC does not center-align or sync 3PWM on Teensy 4 by default; the flag requires FlexPWM-only pins |
| VBAT sense | (not specified) | **Pin 41 (`A17`), 68 k : 10 k + 100 nF**, ≈26 V FS | Undervoltage lockout, runtime `voltage_power_supply` correction, Phase-3 regen trip |
| BEC | "~45 A BEC planned" | **3 A, 5 V — deferred to post-Phase-1** | 45 A was a note error. The VUSB↔VIN cut is irreversible and changes bench behavior; sequenced after Phase 1 |
| Power topology | (not specified) | **XT30 loop key → 7.5 A fuse → star-ground distribution board, 470 µF bulk** | Star ground prevents common-impedance coupling between motor return and signal reference |

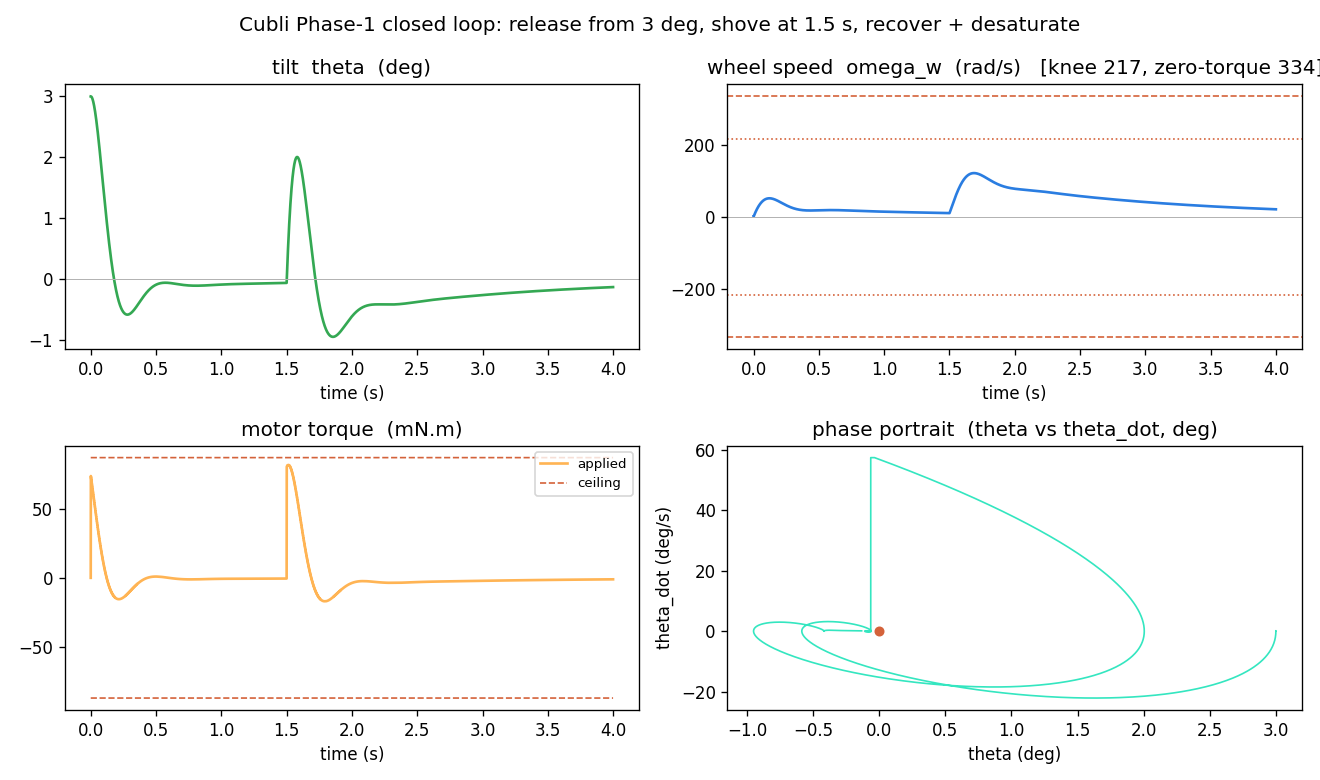
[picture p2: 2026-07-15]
sim/closed_loop.png

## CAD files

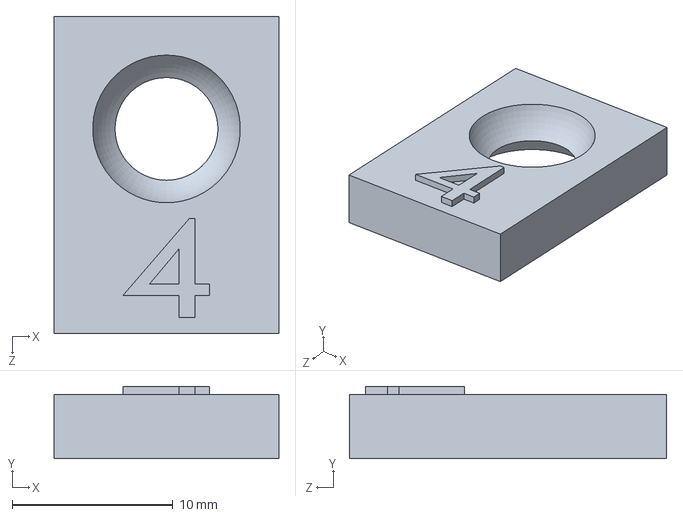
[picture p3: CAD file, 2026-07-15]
cad/BallTst/BALLSWAGE_TEST_4.SLDPRT
14.0 x 4.50 x 19.7 mm

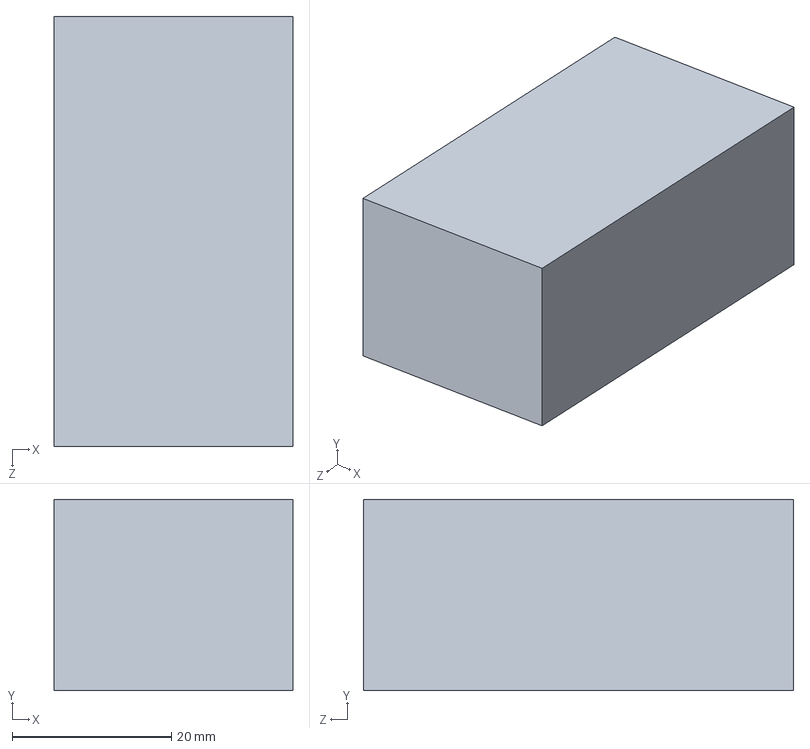
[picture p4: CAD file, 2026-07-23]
cad/BoughtComponents/4s650mAh.SLDPRT
30.0 x 24.0 x 54.0 mm

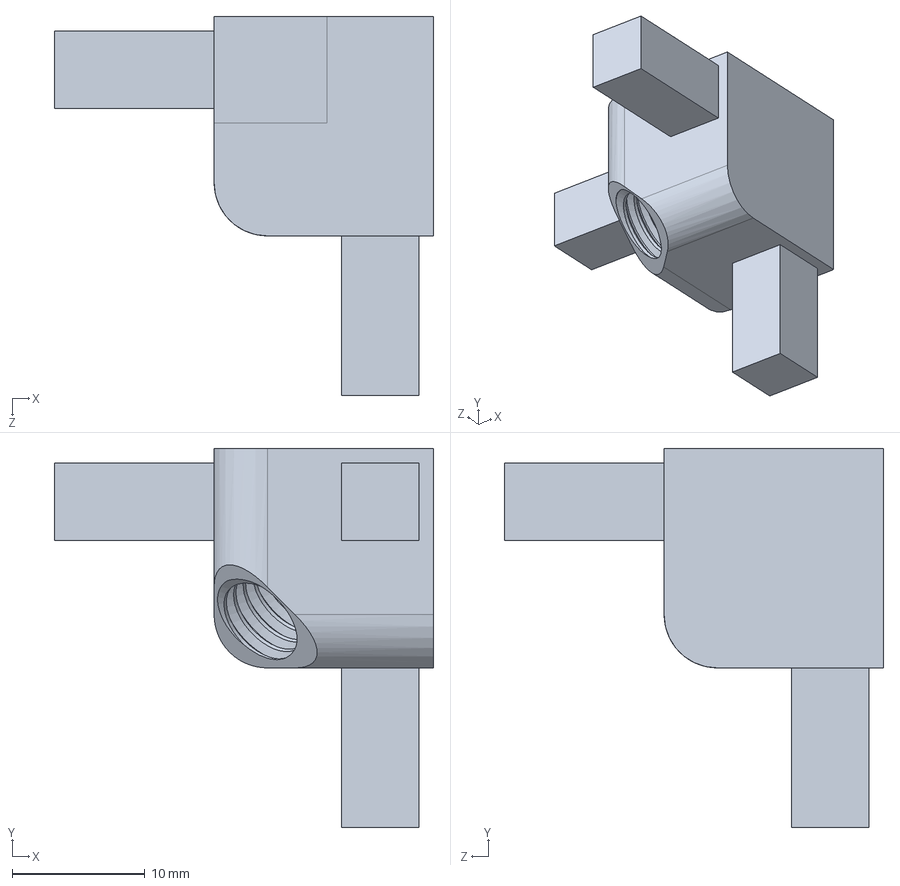
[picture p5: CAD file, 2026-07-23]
cad/Corner_R2.SLDPRT
28.5 x 28.5 x 28.5 mm

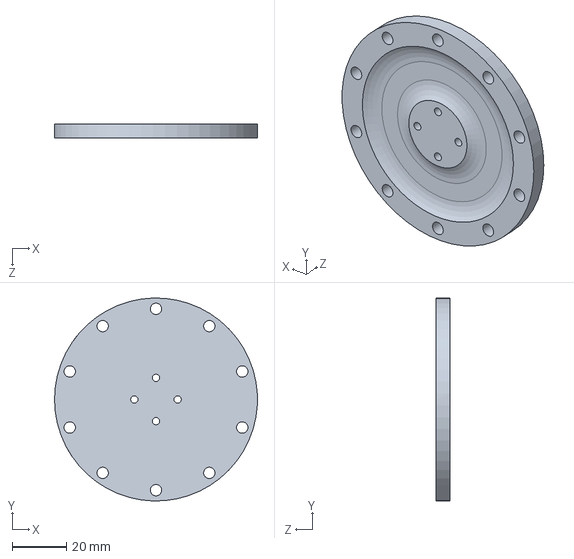
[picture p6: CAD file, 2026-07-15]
cad/Disk/Disk.SLDPRT
75.0 x 75.0 x 5.00 mm

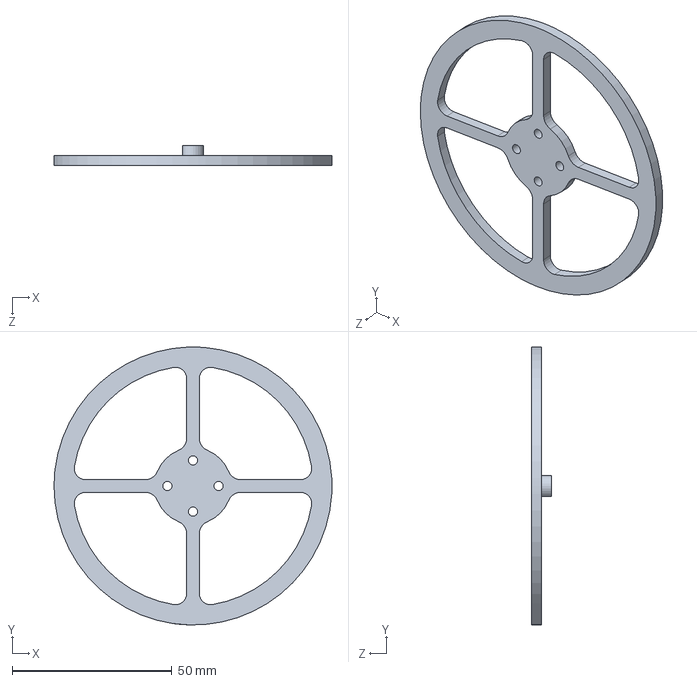
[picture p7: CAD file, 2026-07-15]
cad/Disk/TOSHOP/Brass_Disk.SLDPRT
87.0 x 87.0 x 6.35 mm

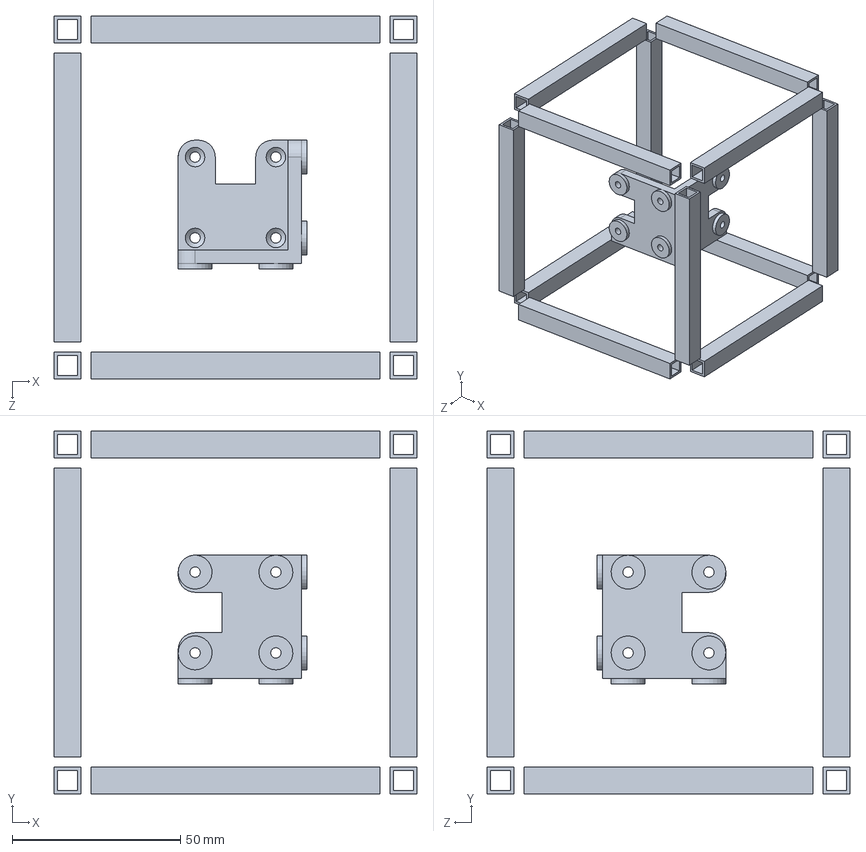
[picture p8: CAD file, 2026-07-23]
cad/Frame/Frame 3_02.SLDPRT
108.0 x 108.0 x 108.0 mm

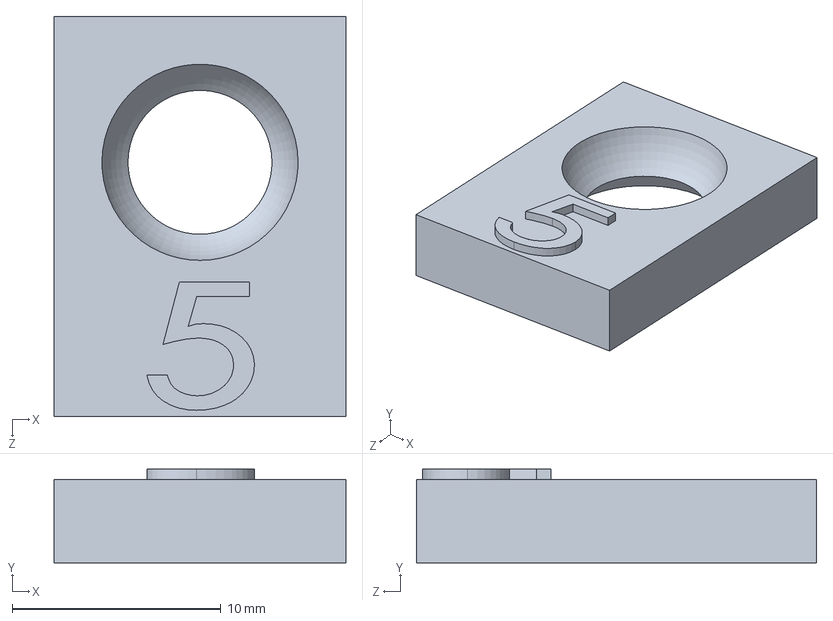
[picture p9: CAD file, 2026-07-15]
cad/BallTst/BALLSWAGE_TEST_5.SLDPRT
14.0 x 4.50 x 19.2 mm

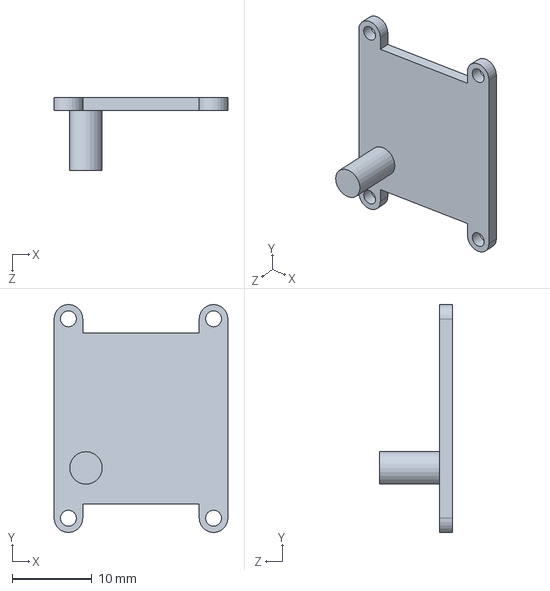
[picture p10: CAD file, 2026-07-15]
cad/BoughtComponents/simpleFOCmini.SLDPRT
21.8 x 28.6 x 9.10 mm

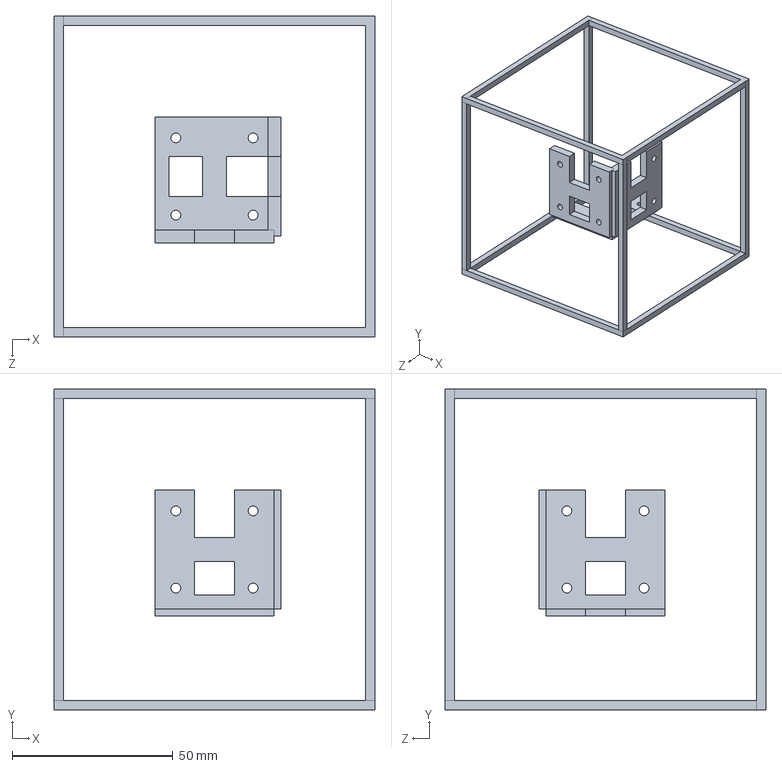
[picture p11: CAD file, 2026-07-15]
cad/Frame/Frame 1/Frame_02.SLDPRT
100.0 x 100.0 x 100.0 mm

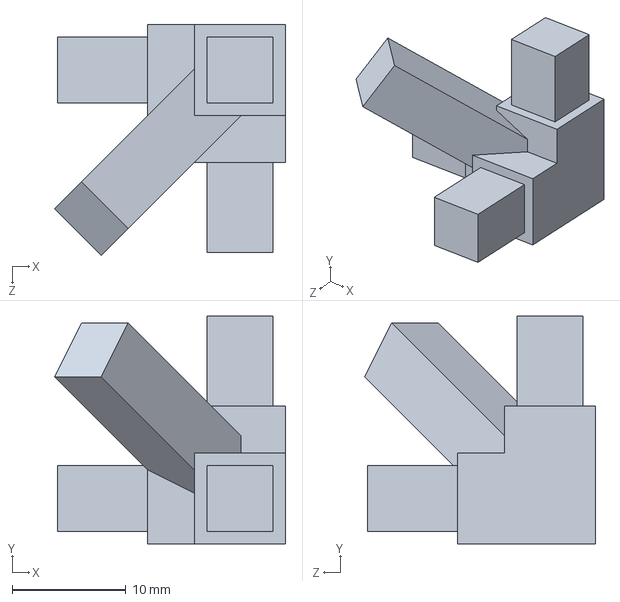
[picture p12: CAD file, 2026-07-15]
cad/Frame/FrameCorner Piece.SLDPRT
20.3 x 20.0 x 20.3 mm

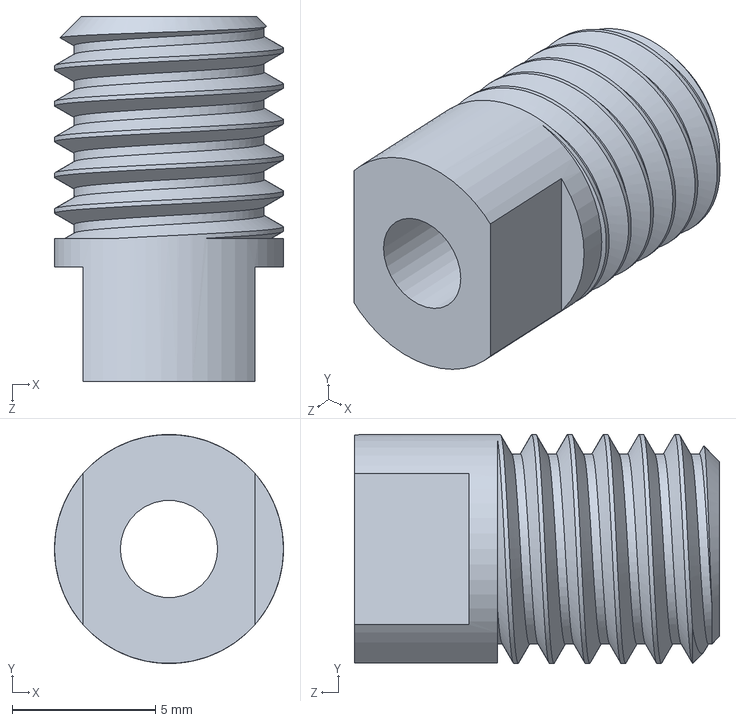
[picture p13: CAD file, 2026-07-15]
cad/SLUG_01.SLDPRT
8.00 x 8.00 x 12.8 mm

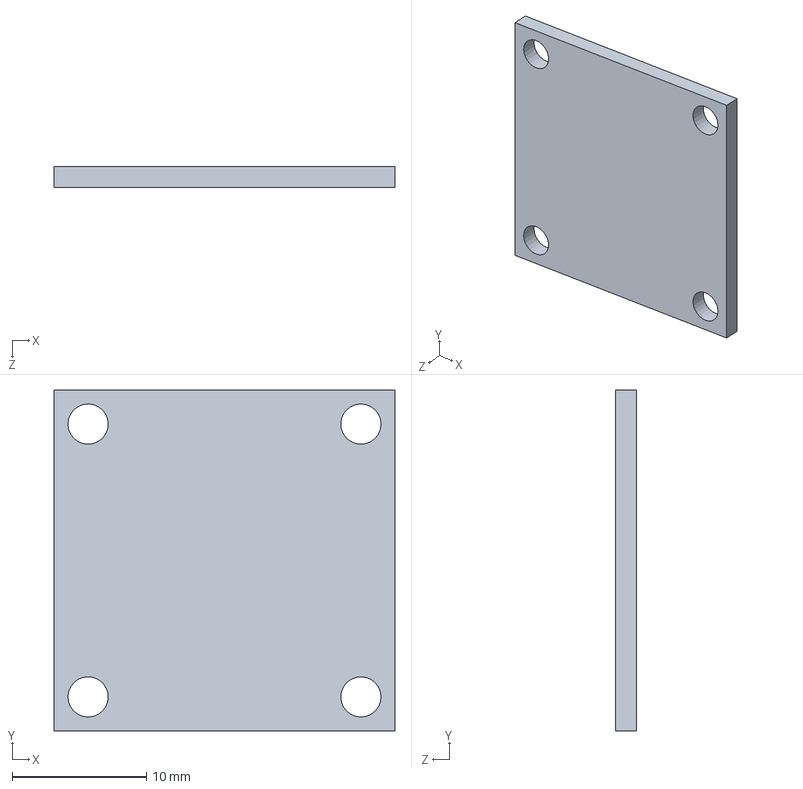
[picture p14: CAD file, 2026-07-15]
cad/BoughtComponents/IMU_Draft.SLDPRT
25.4 x 25.4 x 1.60 mm

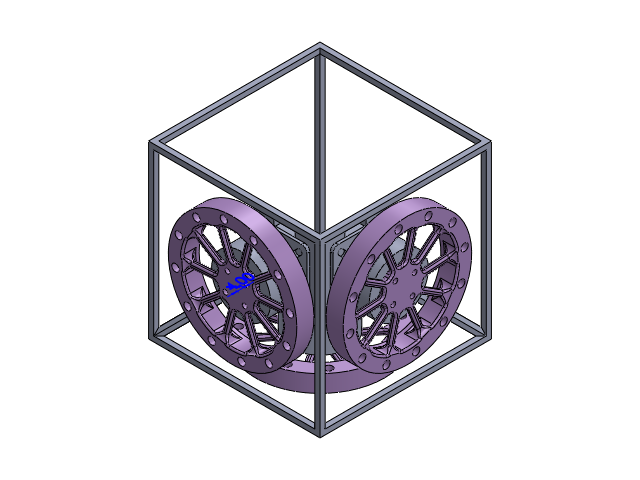
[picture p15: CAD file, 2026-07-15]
cad/Frame/Frame 1/Frame_assem_02.SLDASM
Frame_04
Disk_V2 x 3
2804wEncoder_CAD_01 x 3

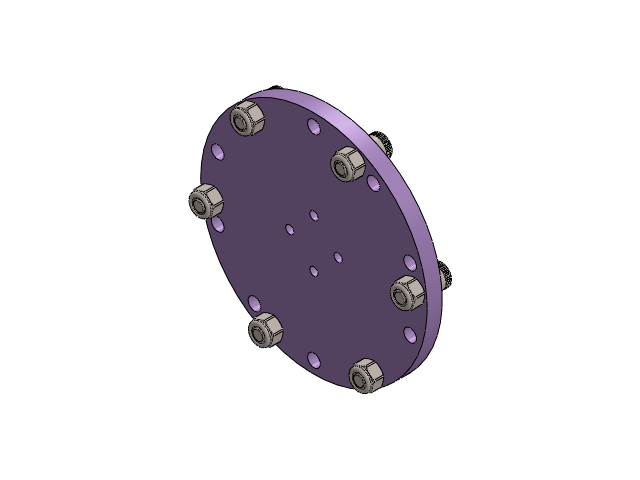
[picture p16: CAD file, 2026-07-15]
cad/Disk/DiskMOI_assembly.SLDASM
Disk
90128A212_Zinc-Plated Alloy Steel Socket Head Screw x 6
90453A112_Thin-Profile Nylon-Insert Locknut x 6

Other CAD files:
cad/Frame/Frame 1/Frame_assem.SLDASM
cad/Disk/Disk2_assembly.SLDASM
cad/BallTst/BALLSWAGE_TEST_1.SLDPRT
cad/Disk/Brass_Disk.SLDPRT
cad/BallTst/BALLSWAGE_TEST_2.SLDPRT
cad/BallTst/BALLSWAGE_TEST_3.SLDPRT
cad/BallTst/BALLSWAGE_TEST_6.SLDPRT
cad/BallTst/BALLSWAGE_TEST_7.SLDPRT
cad/BoughtComponents/2804wEncoder_CAD_01.SLDPRT
cad/Disk/Brass_Disk_PLASTIC.SLDPRT
cad/Disk/Disk_V2.SLDPRT
cad/Disk/TOSHOP/Brass_Disk.DXF
cad/Disk/TOSHOP/Brass_Disk.STL
cad/Frame/Frame 1/Frame_01.SLDPRT
cad/Frame/Frame 1/Frame_03(PRINTED).SLDPRT
cad/Frame/Frame 1/Frame_04.SLDPRT
cad/Frame/Frame 2.SLDPRT
cad/Frame/Frame 2_02.SLDPRT
cad/Frame/Frame 3_01.SLDPRT
cad/McMasterCarr/90453A112_Thin-Profile Nylon-Insert Locknut.SLDPRT
cad/McMasterCarr/90576A161_Medium-Strength Steel Nylon-Insert Locknut.SLDPRT
cad/McMasterCarr/91294A018_Black-Oxide Alloy Steel Hex Drive Flat Head Screw.SLDPRT
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

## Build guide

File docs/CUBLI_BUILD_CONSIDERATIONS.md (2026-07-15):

# Cubli build — design considerations

*The frame is a controls component, not a chassis. Every line below exists to protect the
plant your PID/LQR will later run on.*

---

## ★ The three non-negotiables
If you read nothing else tonight — everything else serves these:

1. **CM at the geometric centre.** The battery **+ brass ballast** are the lever that gets you there.
2. **The three wheel faces truly perpendicular (square).** Keeps the torque-allocation map 1:1.
3. **A rigid frame.** Flex is unmodeled dynamics; the controller assumes a rigid body.

---

## 1. Mass & balance — the controls part
- CM → geometric centre. The three motors bias it toward their shared corner (~4,810 g·mm
  per axis as-modeled); counter with the **4S 650 battery (~75 g) placed toward the
  *opposite* corner** plus **~45–50 g of brass ballast packed deeper into that corner** —
  the 650 pack alone covers only ~59 % of the countermoment. Working numbers in
  `HARDWARE.md` §10; finalize against the full assembly and the weighed pack.
- Products of inertia (Ixy, Ixz, Iyz): the motors on face-centres give you **zero** for free;
  off-centre battery/ballast reintroduce them. Keep both near the [1,1,1] diagonal, then
  **measure the real tensor in SolidWorks and feed it to the controller** — the LQR needs a
  *known* tensor, not necessarily a diagonal one.
- **Total mass is the enemy.** Every gram shrinks the torque-limited recovery envelope
  (~224 g of electronics roughly *halves* it). Don't over-build the frame. (This is exactly
  why 650 mAh + brass beats a 1500+ mAh pack: same CM fix, ~30 g lighter.)
- Assign **real material densities** in SolidWorks (PETG ≈ 1270, brass ≈ 8500, steel ≈ 7700
  kg/m³) or every mass-property number is fiction.

## 2. Geometry & fit
- ~100 mm PETG cube; three motors on three mutually perpendicular faces meeting at one corner;
  spin axes = body axes x / y / z.
- **87 mm wheels** (CAD-confirmed): inter-wheel clearance near the shared corner is the binding
  packing constraint — holds ~2 mm gap at the shared vertex. Wheels must not protrude past the
  cube silhouette or into the ground-contact corner/edges.
- Motor hub must match the **bell bolt pattern** (hole count + bolt-circle diameter).
- Don't obstruct the hollow shaft or the pre-mounted AS5600 magnet ring — leave room and the
  correct **air-gap** for each encoder behind its motor.
- Define the **contact geometry**: the three edges it balances on (**Phase 1**) and the corner
  (**Phase 2–3**). A small, repeatable, slightly rounded contact point beats a sharp printed
  corner that chips and changes your pivot.
- Route channels for phase leads (MX1.25), the Qwiic/I2C runs, and the battery leads.

## 3. Flywheels
- **8.00e-5 kg·m² reflected** (disk 7.63e-5 + rotor 3.7e-6). **CNC-machined C360 brass, spoked,
  87 mm OD, 5.9 mm rim, 1/8″ plate, 65 g** — hit dead-on in CAD, **one-and-done, no trim screws**
  (the tight build can't take rim protrusions, so the inertia is dialed in the model instead).
  (Was printed PETG / 5.0e-5; metal let the OD grow, which lifted the optimum, and 8e-5 = the
  multi-swing-pump-up floor so one wheel covers all phases.)
- **Minimize mass in-plane, never by thinning.** Out-of-plane stiffness goes as **thickness³** —
  keep rim, spokes, and hub at full 1/8″ and remove mass with **through-pockets** between
  **3–4 narrow (~4 mm) full-depth spokes**. Strength is free here (0.087 N·m peak → trivial
  stress); the constraint is **trueness/stiffness**, not strength.
- Read inertia as **Izz about the spin axis**, wheel centred on the shaft axis.
- Keep CM on the spin axis and products zero → no vibration. (A shaky wheel at speed corrupts
  the IMU reading too — balance helps *sensing*, not just dynamics.) **Hold hub-bore-to-rim
  concentricity** in machining — runout = wobble = imbalance.
- **Mount on a center pilot, not the bolts.** A short spigot (~4–5 mm) slip-fits (~0.03 mm) into
  the bell's rotating bore and *centers* the wheel; the M2.5 bolts (2.8–2.9 mm clearance) only
  clamp. Keep the pilot short so the wheel seats on the bell **face**, not bottomed in the bore,
  and well clear of the encoder magnet at the bottom. Brass is non-magnetic, so it won't disturb
  the AS5600 field even near it.
- Mass at the rim is most efficient (inertia ∝ r²); the bigger OD hits the target at lower mass.
- **Tooling (C360):** 2-flute, uncoated, low/neutral-rake (avoid for-aluminium high-helix mills —
  they grab in brass). A 1/4″ mill cuts the whole part if inside fillets are ≥1/8″ R.
- **Keep the blank offcuts** — they're the CM ballast stock (§1).
- **Phase 3 is a multi-swing pump-up on this same wheel** — no heavier wheel needed. But still
  design the hub **modular** to accept a dedicated single-dump hop rim (~16e-5) as a fallback.

## 4. Structure & stiffness
- The three **motor mounts carry the reaction torque** — make them the stiffest parts.
  Rib/triangulate them; print solid or high-infill with layers across the load.
- Frame flex shifts resonances into your control bandwidth and makes the IMU read frame
  *ringing* instead of body attitude.
- Design for **repeated assembly/disassembly** — you'll be in and out of this many times.
  Heat-set inserts / captive nuts beat printed threads; keep fastener access clear.

## 5. Electronics, wiring & power
- Teensy on **USB** (logic); 4S LiPo → SimpleFOC **VM only**; **common ground mandatory**
  (tie battery GND to Teensy GND or the drivers can't read the PWM).
- **Torque control is voltage-mode with *estimated* current** — the SimpleFOC Mini has no
  current sensing, so `current_limit = 2.0 A` is an estimate riding on Rs, not a measurement.
  Set `phase_resistance` and `KV_rating` so the library can estimate well (see `HARDWARE.md` §3).
- Three I2C buses: encoder #1 + IMU on `Wire`; encoders #2/#3 on `Wire1`/`Wire2`. Wire only #1
  for Phase 1, but **route all three now** so Phase 2 isn't a teardown.
- IMU: mount rigidly to a stiff member, ideally near the CM, axes aligned to the body frame —
  and **write down the sensor→body rotation.** You'll need it, and it must transfer verbatim
  to the rocket.
- Keep driver-to-motor leads short; 680 µF/25 V across VM near the drivers; inline fuse and
  correct cap polarity **before** motor power.
- `voltage_limit = 14.5 V`, `current_limit = 2.0 A`. Battery **and ballast** sit in their final
  slots even in Phase 1, so the CM you tune against is the real one.
- Phase 3 only: regen brake chopper (~1.9 J/wheel from the 217 rad/s knee — sized in
  `HARDWARE.md` §9) — not now, just leave bus headroom in mind.

## 6. Build sequence (Phase 1)
- Build the **complete** mechanical cube + all electronics in final position → Phase 1 becomes a
  true *subset* of the final config, so your tuning transfers instead of being throwaway.
- Power **one** motor only (its driver + AS5600 on `Wire`, IMU on `Wire`). The other two are
  installed **dead mass**.
- Balance on the edge whose pivot runs **parallel** to the active wheel's spin axis.
- Idle wheels: leave unpowered — cogging holds them, and their axes don't couple into your tip axis.

---

## Before you cut or print — the CAD loop
Model every part with real densities → drop in McMaster bolt CAD → pull **Mass Properties** on
the *full assembly* (battery + ballast in their slots) → check CM at centre and products near
zero → nudge battery/ballast placement → only then commit. Log the final mass tensor in the
repo — it's both portfolio gold and the controller's input.

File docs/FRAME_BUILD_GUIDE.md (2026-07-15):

# Cubli Frame — Final Build Guide (locked architecture · v4: 7 cable-stay tensioned hub)

> Locked **frame** architecture: a tube cage, a central machined motor hub, and **seven
> pre-tensioned 1/8″ stranded-cable stays** that suspend the hub. No rigid strut — all seven
> stays are identical tensioned members. Supersedes the frame section of `HARDWARE.md` and
> earlier versions of this guide. Electronics, motors, wheels, wiring, and power limits live in
> `HARDWARE.md` and remain the source of truth for those.
>
> **Open until CAD:** the cube edge `E`, the seven cable pin-to-pin lengths, and — keyed to a
> measured sample — the final slug/cup/tap dimensions (§5). Everything else is locked.
>
> *v4 changes from v3: the stay member is now **1/8″ (3.2 mm) 7×7 stranded stainless cable**, not
> a 14 ga J-bend solid spoke. Its near-zero bending stiffness routes through the tight gaps near
> the wheels that the stiff spoke could not, while its axial stiffness ≈ the old 2 mm spoke. Both
> ends terminate in **swaged copper-stop sleeves**; the vertex tensioner is a **machined steel slug**
> threaded into the corner block (this resolves the old nipple-vs-M2 question). The spoke-free 8th
> vertex remains the contact/balance corner.*

---

## 1. Architecture at a glance

Three structural elements:

1. **The cage** — 12 aluminum tubes (cube edges) plugged into 8 corner blocks (vertices). The outer skeleton.
2. **The central hub** — a machined aluminum block at the cube center, carrying the three motors on three mutually perpendicular faces. It touches the cage *only* through the stays.
3. **Seven cable stays** — 1/8″ 7×7 stranded stainless cable in tension, from the hub out to **7 of the 8 vertices**. They both *locate* the hub and *preload* the whole structure.

**The three non-negotiables:**
- **CM at the geometric center.** A *tensioning outcome*, not a bolted datum — see §7 and §8.
- **The three motor faces truly perpendicular** to one another — owned entirely by the hub.
- **A rigid frame** — first resonance well above control bandwidth and the ~35–50 Hz top wheel-spin. All-tension mounts are springier than a strut, so this is preload-dependent (§8).

---

## 2. Why seven (and not four or six)

The hub is a free rigid body: 6 DOF. A taut cable is the *ideal* tension-only member — it removes one DOF, but only while it stays in tension (a cable takes zero compression, so the "only while taut" caveat is absolute here).

- **Six** independent stays can *locate* the hub, but leave no way to pre-tension it (no self-stress state) — they'd only go taut under external load. Useless for a preloaded mount.
- **Seven** adds exactly one *state of self-stress*: a way for all seven to pull against each other and sit in steady tension on their own. **That self-stress is your preload.** (Maxwell's rule: members − 6 = self-stresses − mechanisms; with 0 mechanisms and 1 self-stress → 7 members.)

The count is necessary, not sufficient — the seven must be *arranged* so their pull directions span all six DOF. The three rotations are the catch: a stay resists the hub twisting only if it anchors **off** the hub center (a moment arm). Seven stays all aimed at the center lock the translations and leave the hub free to spin. So the hub anchors sit out on the block's faces and corners, spread so every rotation tightens something — laced like a wheel, not like a sunburst.

---

## 3. The cage

**Tubes (×12)** — 8 × 8 × 1 mm 6063 aluminum square tube, 6 mm bore.
- Best stiffness-per-gram in the robust-wall family; the 6 mm bore gives a stiff corner-block leg (leg stiffness ∝ bore⁴), and the joints — not the tube span — set frame stiffness.
- Cut length **L = E − 2c**, where `c` is the corner-block intrusion per edge (≈ 4 mm at an 8 mm corner body → L = E − 8 mm).
- Buckling margin ~13 kN against tens-of-newtons preload — strength is a non-issue.

**Corner blocks (×8)** — machined aluminum nodes.
- Three legs, each ~5.8 mm, slip-fit the 6 mm tube bore; engagement ≈ 12–16 mm; bond (epoxy) **and** a transverse pin/set screw per leg so preload can't creep a leg out.
- **Seven of the eight** carry a **tapped M8 hole** (local boss if the body's too thin) for the vertex slug tensioner — see §5.
- **The eighth is the contact/balance corner:** left stay-free, and shaped into a clean (ideally hardened) balance tip. No stay means no tensioner hardware where the cube touches the ground.

---

## 4. The central hub

Machined aluminum — the precision datum for the whole machine.
- **Three mutually perpendicular faces**, one per motor — three orthogonal faces of a squared block, no compound angles. Start from precision-ground stock (ground cube / 1-2-3 block); only the motor bolt patterns get drilled, so squareness comes from the stock.
- **Seven copper-stop counterbore cups** — one drilled cup at each anchor: a flat-bottom counterbore (~5.6 mm) that seats the cable's hub-end copper stop, with a ~3.5 mm through-hole the bare cable exits. Distributed around the hub's faces, edges, and corners and **offset from center** so every stay has a moment arm (§2). Each cup is aimed at its vertex; a few degrees of cable flex takes up the diagonal, so the cups don't need precise compound angles. The hub end is the **dead anchor** — no adjustment here.
- Perpendicularity belongs **entirely** to this part. The cage only provides stiffness and contact geometry — never delegate squareness to the frame.

---

## 5. The seven cable stays

Each stay is **1/8″ (3.2 mm) 7×7 stranded stainless aircraft cable** (T316 preferred; 304 is fine indoors), cut to length, in pure tension.

**Why stranded cable (the reason for the v4 change):** its near-zero bending stiffness threads through the tight, wheel-adjacent gaps that the stiff 2 mm spoke could not be routed through — that routing problem is what drove the swap. Axial stiffness is what matters structurally, and 1/8″ 7×7 lands ≈ the old 2 mm spoke. Two cable-specific tradeoffs, both managed:
- **Effective axial modulus ~half a solid rod** (it's stranded) — already accounted for in picking 1/8″; if first mode comes in low the fix is a fatter cable (3/16″), not more tension.
- **Constructional stretch** — handled by the pre-stretch + re-tension-after-settle steps (§7, §8).

Strength is never the gate (1/8″ breaks ~1400 N vs a ~100–300 N worst-case stay). And zero bending stiffness erases the anchor-misalignment bending stress a stiff member would see at a few degrees of hole misalignment — the cable simply doesn't care about the angle.

**Both beads — a swaged copper stop sleeve.** Each end terminates in a copper stop sleeve, 1/8″ size — **5.5 mm OD × 6 mm tall × 3.5 mm bore**. The 3.5 mm bore is the one that clears the cable; the 2.8 mm-bore variant does **not** pass 1/8″ cable and is the wrong part. Crimp with the manual wire-rope tool — copper is soft enough to hand-swage. (That same hand tool *cannot* swage a hard stainless ball/stud terminal — those need a hydraulic press; avoiding that press is the main reason a copper stop beats a single-shank ball here.) Copper (or stainless) sleeves are the correct rigging match for stainless cable — **never aluminum sleeves**: those are spec'd for galvanized cable and are a galvanic + spec mismatch on stainless.

**Hub end (fixed anchor):** the hub-end copper stop drops into its machined counterbore cup in the hub (§4). No adjustment — this is the dead end.

**Vertex end (the tensioner — a machined steel slug):** a small part turned on the Tormach — an externally-threaded steel cylinder with a **flat-bottom internal cup** that captures the vertex-end copper stop. It threads into the corner block (tapped M8); turning it draws the captured stop outward → tensions the cable.
- **Flat-bottom cup** (not conical) because a copper stop is a flat-ended cylinder.
- **Steel / stainless slug** into the aluminum block: no aluminum-on-aluminum thread galling, and a harder seat under the stop.
- The flat cup bottom doubles as a **thrust face** — the slug spins while the flat-ended stop stays put, so tensioning doesn't wind the cable. A dab of anti-seize helps; if the cable visibly winds on the last turns, hold it or back off — any slight wind-up relaxes on settling.

**Dimensions (from the selected 5.5 / 3.5 / 6 stop):**
- **Cup:** flat-bottom counterbore ~5.6–5.7 mm; ~3.5 mm through-hole for the bare cable; ~1 mm bearing shoulder; cup depth ~4 mm (let the stop stand proud) up to the full 6 mm.
- **Slug:** ~7.5–8 mm OD, ~1 mm wall → external **M8** into the block. That's ~one size smaller than a single-shank ball would have forced (~M9–M10), because the cup only has to clear the bare cable, not a ball's larger shank.
- **Corner block:** tap M8; add a local boss if the body's too thin to carry the thread.
- The hub cup is the same cup geometry, machined straight into the hub block (no separate part).

**MEASURE FIRST (hard rule):** crimp one copper stop on a cable scrap, caliper the *swaged* OD, and size every cup/slug/tap to that measured number **before** machining the corner blocks. The crimp moves the OD a few tenths — 5.5 mm is the design starting point, the sample is the truth.

**Shortening cable:** cut with the cable cutter (a clean shear — not side cutters, which splay the strands); seal the cut end (heat-shrink or a whisker of CA/flux) so the lay doesn't unravel before you crimp. Deburr nothing — there's nothing to deburr on a sealed cable end.

---

## 6. Key dimensions — confirm in CAD before cutting

| Quantity | Status | Set by |
|---|---|---|
| Cube edge `E` (outer) | **OPEN** | Inter-wheel clearance interference check (≥ ~2 mm gap at the shared corner; wheels 87 mm OD per `HARDWARE.md`) |
| Tube cut length `L` | Derived | `L = E − 2c` |
| Cable stay pin-to-pin (×7) | **OPEN** | CAD — each hub cup to its vertex slug seat, once `E` and the 7 anchors are placed |
| Slug / cup / corner-block tap | **≈ M8** (cup ~5.6, through-hole ~3.5); final = measured swaged-OD | §5 measure-first |
| Which vertex is free | **Default: the contact/balance corner** | Layout — but confirm against the wheel-clearance check (§9) |
| Reaction wheels | Locked | 87 mm OD, 65 g, 8.00e-5 kg·m² reflected (`HARDWARE.md`) |
| Motors | Locked | QiuLovesYT 2804, 220 KV (`HARDWARE.md`) |

---

## 7. Assembly & tensioning sequence

1. **Assemble the cage** — corner-block legs into the tubes; bond and pin each joint.
2. **Mount the three motors + wheels** to the hub's three perpendicular faces.
3. **Crimp the hub ends** — cut each cable to length; crimp a copper stop on the hub end of each of the seven.
4. **Install** — seat each hub-end stop in its hub cup; route the cable to its vertex; pass the vertex end through its steel slug, crimp the vertex copper stop, drop it into the slug cup; start each slug a few turns into its corner block.
5. **Snug all seven** so the hub sits roughly centered.
6. **Pre-stretch / bed-in** — bring every stay up near working tension and work the structure so the cable's constructional stretch comes out now. This matters more than it did with solid spoke — don't skip it.
7. **Tension it like truing a wheel** — bring the slugs up gradually, in opposing rounds, a little at a time, keeping the hub centered. Don't fully tension one before the others.
8. **Verify** (this is what the rigid strut used to give for free):
   - Hub doesn't wobble under a firm push — no slack, no loose DOF.
   - No stay goes slack when you load/spin a wheel by hand — preload beats the 0.087 N·m motor torque.
   - Hub is centered → CM at the geometric center (check against the SolidWorks target).
9. **Re-tension after it settles** (the cable will have crept), then re-verify centering.
10. **Then electronics** — per the bring-up order in `HARDWARE.md` (logic before motor power).

---

## 8. Watch items (carry through CAD and bring-up)

- **Preload vs motor torque.** A stay that goes slack under the 0.087 N·m reaction torque is instant backlash — the hub shifts, the IMU lies, the controller chases a ghost. Tension high enough that none ever unloads.
- **First mode.** All-tension *and* stranded cable's ~half effective modulus make this springier than a strut or a solid spoke; keep the hub-on-stays resonance well above the ~35–50 Hz spin rate. 1/8″ 7×7 ≈ the old 2 mm spoke axially — if the tap-test comes in low, go to a fatter cable (3/16″), not just higher tension. Tap-test on assembly; measure if in doubt.
- **Constructional stretch / creep.** Stranded cable beds in and lengthens under first tension and first runs. Pre-stretch (§7), re-tension after settling, and re-check that no stay has dropped below its preload threshold after the first spin-ups.
- **Centering is earned, not given.** Uneven tension walks the hub — and the CM — off center. Tension *to* center and verify.
- **Geometry actually spanning 6 DOF.** Intuition is placing the anchors; if the hub shows any free wobble on assembly, the 7×6 wrench-matrix check (rank 6 + an all-positive self-stress vector) pinpoints which DOF is loose. ~10 lines of numpy if you want it.

---

## 9. Gates before cutting metal

- [ ] **Inter-wheel clearance** interference check → locks `E` (≥ ~2 mm at the shared corner, 87 mm wheels).
- [ ] **Seven cable-stay paths clear the spinning wheel disks** — the make-or-break check. The cable's flexibility buys a little routing slack, but for first mode each stay still wants a near-straight chord — don't lean on big bends. Default plan: free the **contact corner** (clean balance tip, no tensioner there). **Fallback if a path won't clear:** move the *adjuster* — seat a stay's fixed copper-stop anchor at the contact corner (clean counterbore, no protruding hardware at the tip) with its steel slug tensioner up at the **hub** instead, and free a wheel-blocked vertex.
- [ ] **Crimp a sample copper stop, caliper the swaged OD, finalize cup/slug/M8** — before machining the corner blocks (§5).
- [ ] Place the 7 hub cups (offset for moment arms) and measure each pin-to-pin → cable cut lengths.
- [ ] Centering plan: how you'll confirm the hub is centered as you tension.
- [ ] Fit-test coupon for the corner-leg slip fit in the real bore.
- [x] Regenerate the frame summaries in `HARDWARE.md` and `PROJECT_BRIEF.md` to match this guide — **done in this pass** (one-line frame descriptions only; the wheel/electronics/power content in those files is unchanged).

---

## 10. Bill of materials — frame only

- 8 × 8 × 1 mm 6063 aluminum square tube — 12 cuts (buy spares; e.g. 4 × 420 mm sticks = 3 cuts each).
- Aluminum stock for 8 corner blocks (7 tapped M8 for slugs, local boss as needed; 1 shaped as the balance tip) — machined.
- Precision-ground aluminum block / 1-2-3 block for the hub — machined, with 7 copper-stop counterbore cups.
- 1/8″ (3.2 mm) 7×7 stainless aircraft cable (T316 preferred; 304 OK indoors) — length ≈ sum of the 7 stays + crimp/trim allowance (100 ft spool on hand).
- 14 × copper stop sleeves, 1/8″ (5.5 mm OD / 3.5 mm bore / 6 mm) — 2 per stay × 7, plus spares.
- Manual wire-rope crimping tool (copper stops) + cable cutter (on hand).
- Steel / stainless stock for 7 machined slug tensioners (flat-bottom cup ~5.6 mm, through-hole ~3.5 mm, external ~M8).
- Threadlocker on the slug threads; anti-seize on the cup thrust face; epoxy + transverse pins/set screws for the corner-leg joints.
- **Note:** copper (not aluminum) sleeves on the stainless cable.

*Live status — where the build is, recent decisions — stays in conversation, not in this doc.*

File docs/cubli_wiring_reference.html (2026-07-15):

# Cubli — Electrical Wiring Reference

Harness ICD · sources: HARDWARE.md §§1–7 (locked) + proposed pin map (not yet absorbed into HARDWARE.md) · Rev C · 2026-07-14

Bring-up order is not optional. 1) Logic on USB only, no battery → I2C bus scan, confirm 0x36 / 0x6B enumerate. 2) IMU first light (raw accel + gyro clean over serial). 3) Madgwick → valid stable quaternion. 4) Only then connect 4S to the driver VM rails, with common ground already tied.

## Sheet 1 — Power Architecture & Ground Topology

Motor power (VM, 14.8 V nom) Ground (star return) Logic / PWM (3.3 V) I2C

Three things that will kill the board. (1) Do not power the Teensy from the SimpleFOC Mini's 3.3 V LDO — it sources 10 mA and cannot run the MCU. (2) Do not cut the VUSB↔VIN pad yet — while USB and the 4S coexist on the bench you want them isolated; the cut only happens when the BEC is physically in place. (3) Common ground gets tied at the star node on the distribution board, not opportunistically at whatever GND pin is nearest.

### Power budget check

Rail | Source | Load | Margin
3.3 V logic | Teensy onboard reg (USB 5 V) | IMU + 3× AS5600 ≈ 40–60 mA | Comfortable (~250 mA rail)
VM (14.8 V nom) | 4S 650 mAh via XT30 + 7.5 A fuse | 3 × 2 A peak = 6 A ≈ 9 C | Fuse sits above 6 A peak, below wiring limit

## Sheet 2 — Signal Pin Map & Connector ICD

### I2C bus map — locked (HARDWARE.md §6)

Bus | SDA | SCL | Devices | Addr | Phase
Wire | 18 | 19 | AS5600 #1 + ISM330DHCX | 0x36 / 0x6B | 1
Wire1 | 17 | 16 | AS5600 #2 | 0x36 | 2
Wire2 | 25 | 24 | AS5600 #3 | 0x36 | 2

Why three buses: the AS5600's address is hardwired to 0x36 with no address pins, so three of them cannot coexist on one bus. The Teensy 4.1's three native I2C peripherals are exactly why this board was chosen — no multiplexer. Every device board ships its own pull-ups, so one device (or the IMU+encoder pair) per bus is fine; don't add more.

### What each SimpleFOC Mini pin connects to

Mini pin | Connects to | Domain
VM, GND (power header) | Distribution board → 4S bus | Motor power (14.8 V)
A, B, C | Motor phases U / V / W (MX1.25) | Motor power
IN1, IN2, IN3 | Three Teensy FlexPWM pins (below) | 3.3 V logic
EN | One Teensy digital pin, per motor | 3.3 V logic
GND (logic header) | Teensy GND — routed in the same bundle as IN1–3 / EN | Signal reference
3V3 out | Nothing. Leave floating. | —

Two ways to cook the board here. (1) The logic-side GND is the reference the DRV8313 compares your PWM against — it rides in the signal bundle, not with the motor return. (2) That 3V3 out pin is a 10 mA LDO; tying it to the Teensy's 3.3 V rail parallels two regulators against each other. Leave it open.

### Motor drive pins — Rev C, regrouped for one FlexPWM module per motor

Motor | IN1 | IN2 | IN3 | EN | FlexPWM module / submodule | Harness bundle | Encoder bus
M1 (Phase 1) | 4 | 5 | 6 | 3 | PWM2 · sm0A / sm1A / sm2A | pins 3–6 contiguous | Wire
M2 | 22 | 23 | 2 | 21 | PWM4 · sm0A / sm1A / sm2A | 21–23 + stray at 2 | Wire1
M3 | 8 | 7 | 1 | 9 | PWM1 · sm3A / sm3B / sm0X | 7–9 + stray at 1 | Wire2
VBAT sense | Pin 41 (= A17) — 68 k : 10 k divider, 100 nF across the 10 k, ≈26 V full-scale | | | | | | —

Why these pins and not others. All three phases of a motor must share one FlexPWM module so they share a carrier. On the Teensy 4.1 that leaves almost no freedom: Wire2 eats pins 24/25, which kills FlexPWM1's submodule-2 and submodule-3 X channels, leaving only {0, 1, 7, 8} on that module. FlexPWM3 exposes just one submodule, so it cannot drive a motor at all. FlexPWM4's third submodule only surfaces at pin 2 or 3. The result is forced: PWM2 → M1, PWM4 → M2, PWM1 → M3. Two stray wires is the floor, not a compromise.

Changed from Rev B. The old M3 (8 / 7 / ~~29~~) straddled FlexPWM1 and FlexPWM3 — two independent carriers on one motor. That was a real defect, not a cosmetic one. EN moved off 30/31/32 to 3 / 21 / 9 so each motor's five wires (3× PWM + EN + GND) leave the board from one place.

Set the center-align flag. #define SIMPLEFOC_TEENSY4_FORCE_CENTER_ALIGNED_3PWM — SimpleFOC does not center-align or sync 3PWM on Teensy 4 by default. The flag does both, and requires every PWM pin to be FlexPWM (never QuadTimer). All nine pins above satisfy that; pins 10–15, 18, 19 are QuadTimer and must never be used for a phase.

Per-motor EN pins are a bring-up safety feature, not a convenience. Three separate EN lines let you hardware-isolate two motors while you characterize the third. Bring up M1 alone; the other two stay disabled at the driver, not just "commanded to zero" in firmware.

### SimpleFOC config — per motor (HARDWARE.md §7)

Parameter | Value | Why
BLDCMotor(7) | 7 pole pairs | 12N14P
phase_resistance | 2.55 Ω | Enables current estimation (no shunts on the Mini)
phase_inductance | 0.00086 H
KV_rating | 220 | Enables back-EMF estimation
torque_controller | TorqueControlType::voltage | Only mode this driver supports
voltage_limit | 14.5 V | Below the 16.8 V full-charge bus; flat torque to ~217 rad/s
current_limit | 2.0 A | Motor hard max — estimated, not measured

### VBAT sense divider — what it is and why it exists

68 kΩ from the 4S bus to a node, 10 kΩ from that node to ground, node → pin 41. Ratio = 10/(68+10) = 0.128. A full pack at 16.8 V lands at 2.15 V — safely inside the Teensy's 0–3.3 V ADC window. Inverted, 3.3 V corresponds to ≈25.7 V of bus, which is the "26 V full-scale."

Job | Why it matters
LiPo undervoltage cutoff | Kill the motors at ~12 V (3.0 V/cell) before the pack is damaged.
Correct voltage_power_supply | In voltage-mode torque control the commanded torque is a voltage. If the bus sags and firmware doesn't know, your torque quietly drifts — and so does your tuning.
Phase-3 regen overvoltage | Trip the brake chopper before the bus hits the motor's 20 V abs max.

Put a 100 nF cap across the 10 k. The divider's Thévenin impedance is 68k‖10k ≈ 8.7 kΩ, right at the edge of what the Teensy's SAR ADC wants to see. The cap gives the sampling capacitor a local charge reservoir. Quiescent draw is 16.8 V / 78 kΩ ≈ 215 µA — negligible against 650 mAh. This is a spacecraft EPS telemetry channel, verbatim.

### Connector ICD

Interface | Connector | Signals | Notes
Motor phases | MX1.25, 3-pin | U / V / W | Staked with RTV at the motor junction
Driver VM power | JST XH, 2-pin | VM / GND | Twisted pair back to star node
Driver control | JST GH, 5-pin (gold) | IN1 / IN2 / IN3 / EN / GND | GND in the same bundle as the signals it references
Encoder / IMU I2C | Qwiic / JST GH | 3V3 / GND / SDA / SCL | One bus per encoder; keep runs short

Color-band and label all three axis harnesses at both ends. Three identical subsystems is a cross-wiring trap, and a swapped M2/M3 phase bundle presents as a controller sign error you will chase in software for a weekend. Band M1 red / M2 green / M3 blue at both connector ends.

Mounting. Boards on short standoffs, short load path into a structural member, target first mode ≳100 Hz (above the 0–50 Hz wheel excitation band). Strain-relieve the harness at every board. The failure mode here is connector fatigue, not structure — an under-constrained board gives you intermittent I2C that looks exactly like a firmware bug.

## Re-connect & verify checklist

What may and may not go on the breadboard. Yes: Teensy, IMU, encoders, I2C, the PWM/EN signal lines, the VBAT divider. That's steps 1–6 and it's exactly what a breadboard is for. No: the VM rail and the motor phases. Breadboard contacts are rated ~1 A against your 6 A peak, contact resistance is tens of milliohms, and the loop inductance turns every PWM edge into ringing. Phases and VM run point-to-point in real wire, with the bulk cap sitting at the driver — not three inches away across a spring contact. Also no: the BEC. USB-only today.

# | Step | Pass criterion

1 | Battery disconnected, loop key out. Teensy on USB only. | Board enumerates; blink sketch runs.
2 | Continuity check: every GND in the harness → star node. Ohm out each phase bundle end-to-end. | <1 Ω to star; no phase-to-phase or phase-to-GND short.
3 | Wire IMU + AS5600 #1 to Wire (18/19). I2C scan. | 0x36 and 0x6B both enumerate.
4 | Scan Wire1 (17/16) and Wire2 (25/24). | 0x36 on each — one device per bus.
5 | Stream raw accel + gyro. Rotate the cube by hand about each axis. | Axes and signs match the body-frame convention; gyro bias small and stable; noise sane.
6 | Stream AS5600 angle. Rotate each rotor by hand. | Monotonic 0–4095 wrap; no dropouts (dropouts = magnet gap or I2C wiring).
7 | All EN lines LOW. Now insert the loop key. | VBAT sense on pin 41 reads within ~2% of a meter on the pack.
8 | Enable M1 only. Open-loop voltage_limit ramp, low value first. | Smooth rotation, no cogging screech, driver not hot.
9 | SimpleFOC initFOC() on M1 — sensor alignment. | Reports a sane zero-electric-angle and sensor direction; repeats on re-run.

Step 7 is the boundary. Everything before it is recoverable; a wiring error after it is a dead driver, a dead Teensy, or a LiPo event. Do not skip step 2 because "it worked last time" — you are re-mating connectors, which is exactly when a strand bridges.

Rev C — 2026-07-14. Changes vs Rev B: PWM/EN map regrouped to one FlexPWM module per motor (M1 3–6, M2 21–23 + 2, M3 7–9 + 1); old M3 straddled FlexPWM1 and FlexPWM3 and is withdrawn. Center-align flag now required. BEC (3 A) drawn as a not-installed untethered branch. VBAT divider gains a 100 nF ADC cap.
Sources: HARDWARE.md §§1–7 (locked — parts, limits, I2C bus map) · PJRC Teensy 4.1 FlexPWM timer table (https://www.pjrc.com/teensy/td_pulse.html) · SimpleFOC — Choosing PWM pins (https://docs.simplefoc.com/choosing_pwm_pins).
HARDWARE.md regeneration is due: this pin map is now a decision, not a proposal. Version-control this file as the harness ICD.

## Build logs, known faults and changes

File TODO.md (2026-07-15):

# Cubli — Rolling To-Do

*Working backlog. Check items off, add as they surface. Newest priorities at the top of each
section. The "Standing reminders" at the bottom are permanent — they don't get checked off.*

Last touched: 2026-07-14

---

## 🔥 Now — close the loop on M1 (Phase 1 firmware)

- [ ] `initFOC()` sensor alignment on M1 — resolves the open-loop sign flip (encoder read −5 for cmd +5)
- [ ] After alignment succeeds, return `voltage_limit` 3 V → **14.5 V** (closed loop only)
- [ ] Closed-loop torque test on M1 — command a torque, confirm the wheel holds/accelerates as expected
- [ ] IMU first light — raw accel + gyro clean over serial (start from `firmware/Madgwick_test`)
- [ ] Madgwick filter → valid, stable quaternion at rest and under hand rotation
- [ ] Quaternion → edge-tilt (`theta`) extraction about the active axis
- [ ] 1 kHz control-loop scheduler + telemetry skeleton
- [ ] AS5600 wheel-speed estimator — **filter it** (raw diff at 1 kHz = ±1.5 rad/s quantization; see reminders)
- [ ] Port PD + desaturation controller from `sim/controller.py` to C++ (Kp 1.40, Kd 0.080, Kw **+**1e-4)
- [ ] Safety layer: tilt cutoff, overspeed cutoff, watchdog
- [ ] PC-side log decoder + plot script mirroring `sim/run.py`
- [ ] Tune on the edge → **🎯 Phase 1 deliverable: video of the cube balancing on an edge**

## 🔧 Build — mechanical + electrical

- [ ] Build the VBAT sense divider (68k:10k + 100 nF → pin 41) — currently **not built**, pin floats
- [ ] Star-ground distribution board — 470 µF bulk, home-run each driver GND (no daisy-chain)
- [ ] Final frame tensioning — pre-stretch the cable stays, re-tension after settle, verify hub centered
- [ ] Confirm cube edge `E` in CAD (inter-wheel clearance ≥ ~2 mm) → locks tube cut lengths
- [ ] Machine the brass CM ballast (~45–50 g) from wheel offcuts; finalize mass + position
- [ ] Full-assembly mass tensor in SolidWorks (battery + ballast in final slots) → feed `sim/params.py`

## 📈 Sim — remaining

- [ ] Re-run `params.py` with the measured mass tensor once SolidWorks gives it
- [ ] Sensor realism in `run.py` — add quantization, noise, bias, I2C latency
- [ ] Robustness sweep: vary m, l, I_bar ±30–50 % and confirm the gains still hold
- [ ] IMU accel/gyro full-scale range selection (and widen the gyro for the Phase-3 hop)

## 📂 Repo / portfolio

- [ ] Add GitHub topics (gear by "About"): reaction-wheel, control-systems, sensor-fusion, teensy, bldc, foc, imu, adcs, aerospace, inverted-pendulum
- [ ] Export a few STEP or rendered PNGs of key parts (hub, wheel) into `cad/` — browser-viewable
- [ ] Embed the Phase-1 balancing video in the README when it exists
- [ ] Optional: contact / LinkedIn line under your name in the README

## 🔭 Later — Phase 2 (3-axis corner balance)

- [ ] Wire encoders #2/#3 to `Wire1` (17/16) and `Wire2` (25/24)
- [ ] Activate M2 + M3 (drivers, phases, EN 21 / 9)
- [ ] Extend the sim to a 3-DOF rigid body
- [ ] LQR design on the linearized plant — choose Q, R
- [ ] Corner balance (hand-placed start) → **🎯 deliverable: video w/ disturbance rejection**

## 🔭 Later — Phase 3 (hop-up)

- [ ] Brake chopper (power resistor + MOSFET on bus overvoltage) — required before ANY hop
- [ ] Multi-swing pump-up trajectory on the same ~8e-5 wheel
- [ ] Catch with the Phase-2 corner controller → **🎯 deliverable: video of the hop**

---

## 📌 Standing reminders (do not delete — these already bit once)

- **SimpleFOC library = 2.3.5.** NOT 2.4.0 (its Teensy-4 driver outputs zero PWM silently). `HARDWARE.md` §11.4.
- **Open-loop `voltage_limit` = 2–3 V, never 14.5 V.** No back-EMF at standstill → `I = U/Rs`; 14.5 V = 5.7 A into a 2 A motor.
- **Wheel-speed quantization:** raw AS5600 diff at 1 kHz = ±1.5 rad/s of noise (12-bit / 1 ms). Filter or lengthen the diff window before feeding the `Kw` desaturation term.
- **`Kw` sign is +.** Negative places a right-half-plane pole → wheel runs away. `sim/controller.py` proves it.
- **Don't cut the VUSB↔VIN pad** until the BEC is physically ready — and that's post-Phase-1, not now.
- **Bench boundary = the loop key.** Everything before it (logic, I2C, encoders) is free; a wiring error after it is a dead board or a LiPo event. Continuity-check grounds on every re-mate.
- **Git rhythm:** `git pull` when you sit down, `git add -A && git commit && git push` when you stop. Pull before, push after.
- **`initFOC()` resolves the M1 sign flip** — don't "fix" it by rewiring phases.

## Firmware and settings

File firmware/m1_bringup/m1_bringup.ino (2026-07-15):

/* ============================================================================
 *  Cubli — M1 Bench Bring-Up  (Teensy 4.1 + SimpleFOC Mini + AS5600)
 *  Rev C pin map. One flash covers the whole bench session — no re-flashing.
 *
 *  WHAT THIS DOES
 *    1. Scans all three I2C buses and reports what enumerates.
 *    2. Streams the M1 AS5600 angle so you can confirm the encoder sees rotation.
 *    3. Runs M1 OPEN-LOOP velocity at a hard-capped voltage.
 *    4. Keeps M2 and M3 hardware-disabled at the driver the entire time.
 *
 *  WHY THE VOLTAGE CAP EXISTS  ** READ THIS **
 *    In open loop there is no back-EMF at low speed and the Mini has no current
 *    shunts. The winding current is just Ohm's law:
 *
 *        I = U / Rs = U / 2.55 ohm
 *
 *    The motor's hard max is 2.0 A  ->  U_max = 2.0 * 2.55 = 5.1 V.
 *    Your Phase-1 voltage_limit of 14.5 V is a CLOSED-LOOP number. Applying it
 *    open-loop would draw 14.5 / 2.55 = 5.7 A and cook the winding.
 *    This sketch clamps to 3.0 V (= 1.18 A). Do not raise the cap.
 *
 *  SAFETY MODEL
 *    - Boots DISABLED. Nothing moves until you type 'e'.
 *    - M2/M3 EN pins are driven LOW in setup() and never touched again.
 *    - Auto-disable after SPIN_TIMEOUT_MS of continuous spinning.
 *    - 'x' = kill everything, any time.
 *
 *  SERIAL COMMANDS (115200 baud, newline-terminated)
 *    ?          help
 *    s          re-scan all three I2C buses
 *    a          toggle AS5600 angle stream (turn the rotor BY HAND to test)
 *    b          read VBAT through the divider on pin 41
 *    e          ENABLE M1
 *    d          DISABLE M1
 *    u <volts>  set open-loop voltage (0 .. 3.0)
 *    v <rad/s>  set open-loop target velocity (signed)
 *    x          EMERGENCY STOP
 * ========================================================================= */

// NOTE: SIMPLEFOC_TEENSY4_FORCE_CENTER_ALIGNED_3PWM is set in build_opt.h, NOT here.
// A #define in this file would not reach SimpleFOC's own .cpp files — Arduino compiles
// libraries as separate translation units. It must be a compiler flag.
// (Not needed for this open-loop test anyway; required before closing the loop.)
#include <SimpleFOC.h>
#include <Wire.h>

// ---------------------------------------------------------------- pin map (Rev C)
// M1 -> FlexPWM2 (sm0A/sm1A/sm2A).  M2 -> FlexPWM4.  M3 -> FlexPWM1.
constexpr int M1_IN1 = 4,  M1_IN2 = 5,  M1_IN3 = 6,  M1_EN = 3;
constexpr int M2_EN  = 21;      // held LOW — hardware isolation
constexpr int M3_EN  = 9;       // held LOW — hardware isolation
constexpr int PIN_VBAT = 41;    // A17, behind the 68k:10k divider

// ---------------------------------------------------------------- motor constants
constexpr int   POLE_PAIRS   = 7;        // 12N14P
constexpr float PHASE_RES    = 2.55f;    // ohm   (HARDWARE.md §2)
constexpr float PHASE_IND    = 0.00086f; // H
constexpr float KV_RATING    = 220.0f;   // RPM/V
constexpr float I_MAX        = 2.0f;     // A, absolute
constexpr float V_SUPPLY_NOM = 14.8f;    // 4S nominal

// HARD CAP. 3.0 V / 2.55 ohm = 1.18 A. Never raise this for open loop.
constexpr float OPENLOOP_V_CAP = 3.0f;

constexpr uint32_t SPIN_TIMEOUT_MS = 20000;  // auto-disable after 20 s of spin
constexpr float    VBAT_DIV_INV    = 7.8f;   // (68k + 10k) / 10k

// ---------------------------------------------------------------- objects
BLDCMotor      motor  = BLDCMotor(POLE_PAIRS);
BLDCDriver3PWM driver = BLDCDriver3PWM(M1_IN1, M1_IN2, M1_IN3, M1_EN);
MagneticSensorI2C sensor = MagneticSensorI2C(AS5600_I2C);   // 0x36 on Wire (18/19)

// ---------------------------------------------------------------- state
bool     motorEnabled = false;
bool     streamAngle  = false;
float    targetVel    = 0.0f;      // rad/s, electrical-frame-agnostic (shaft)
uint32_t spinStartMs  = 0;
uint32_t lastPrintMs  = 0;

// =========================================================================
//  I2C scan — the 60 seconds that protects everything downstream
// =========================================================================
void scanBus(TwoWire &bus, const char *name, const char *pins) {
  Serial.printf("  %-6s (%s): ", name, pins);
  int found = 0;
  for (uint8_t addr = 1; addr < 127; addr++) {
    bus.beginTransmission(addr);
    if (bus.endTransmission() == 0) {
      Serial.printf("0x%02X ", addr);
      found++;
    }
  }
  if (!found) Serial.print("-- NOTHING --");
  Serial.println();
}

void scanAll() {
  Serial.println("\n--- I2C SCAN ---");
  scanBus(Wire,  "Wire",  "SDA 18 / SCL 19");
  scanBus(Wire1, "Wire1", "SDA 17 / SCL 16");
  scanBus(Wire2, "Wire2", "SDA 25 / SCL 24");
  Serial.println("EXPECT: Wire -> 0x36 (AS5600 #1) AND 0x6B (IMU)");
  Serial.println("        Wire1 -> 0x36   |   Wire2 -> 0x36");
  Serial.println("If an encoder is missing: check 3V3, GND, and that SDA/SCL");
  Serial.println("are not swapped on the connector you just re-mated.\n");
}

float readVbat() {
  // 12-bit, 3.3 V reference. V_bus = V_pin * (68k + 10k) / 10k
  int raw = analogRead(PIN_VBAT);
  return (raw / 4095.0f) * 3.3f * VBAT_DIV_INV;
}

void killAll() {
  targetVel = 0.0f;
  motor.move(0);
  motor.disable();         // motor.disable(), not driver.disable() — see setup()
  motorEnabled = false;
  digitalWriteFast(M2_EN, LOW);
  digitalWriteFast(M3_EN, LOW);
  Serial.println("!! ALL MOTORS DISABLED !!");
}

void help() {
  Serial.println("\n=== COMMANDS ===");
  Serial.println("  ?          this help");
  Serial.println("  s          re-scan I2C buses");
  Serial.println("  a          toggle AS5600 angle stream (turn rotor by hand)");
  Serial.println("  b          read VBAT (pin 41)");
  Serial.println("  e / d      enable / disable M1");
  Serial.printf ("  u <volts>  open-loop voltage  (0 .. %.1f V hard cap)\n", OPENLOOP_V_CAP);
  Serial.println("  v <rad/s>  open-loop target velocity (signed)");
  Serial.println("  x          EMERGENCY STOP\n");
}

// =========================================================================
void setup() {
  Serial.begin(115200);
  while (!Serial && millis() < 3000) { }

  // ---- FIRST: hardware-isolate M2 and M3. Before anything else can go wrong.
  pinMode(M2_EN, OUTPUT); digitalWriteFast(M2_EN, LOW);
  pinMode(M3_EN, OUTPUT); digitalWriteFast(M3_EN, LOW);

  analogReadResolution(12);

  Serial.println("\n============================================");
  Serial.println(" Cubli M1 bench bring-up — Rev C pin map");
  Serial.println(" M2/M3 held DISABLED at the driver.");
  Serial.printf ( " Open-loop voltage cap: %.1f V  (= %.2f A into %.2f ohm)\n",
                  OPENLOOP_V_CAP, OPENLOOP_V_CAP / PHASE_RES, PHASE_RES);
  Serial.println("============================================");

  Wire.begin();  Wire.setClock(400000);
  Wire1.begin(); Wire1.setClock(400000);
  Wire2.begin(); Wire2.setClock(400000);
  delay(50);

  scanAll();

  // ---- encoder (M1, on Wire). Used only as an INDEPENDENT measurement here —
  //      open-loop control does not close on it. That is the whole point: if the
  //      commanded velocity and the measured velocity disagree, you learn something.
  sensor.init(&Wire);
  Serial.printf("AS5600 #1 initial angle: %.3f rad\n", sensor.getAngle());

  // ---- driver
  driver.voltage_power_supply = V_SUPPLY_NOM;
  driver.voltage_limit        = OPENLOOP_V_CAP;   // clamp at the driver too
  driver.pwm_frequency        = 25000;            // 25 kHz — above audible, << L/R = 337 us
  if (!driver.init()) {
    Serial.println("FATAL: driver.init() failed. Check EN/IN wiring. Halting.");
    while (1) { }
  }
  motor.linkDriver(&driver);

  // ---- motor, OPEN LOOP
  motor.phase_resistance  = PHASE_RES;
  motor.phase_inductance  = PHASE_IND;
  motor.KV_rating         = KV_RATING;
  motor.voltage_limit     = OPENLOOP_V_CAP;       // <-- the number that matters today
  motor.current_limit     = I_MAX;
  motor.velocity_limit    = 40.0f;                // rad/s, gentle for a bench spin
  motor.controller        = MotionControlType::velocity_openloop;

  motor.useMonitoring(Serial);
  motor.init();
  motor.disable();         // boot disabled. nothing spins until you say so.
                           // NOTE: motor.disable(), not driver.disable() — the
                           // motor keeps its OWN enabled flag, and BLDCMotor::move()
                           // early-returns if it's false. Driving EN high alone is
                           // not enough; the library must also know it's enabled.

  Serial.println("\nReady. Motor is DISABLED.");
  Serial.println("Suggested order:  s  ->  a (spin rotor by hand)  ->  b  ->  u 2.0  ->  e  ->  v 5");
  help();
}

// =========================================================================
void loop() {
  // ---- serial command parser
  if (Serial.available()) {
    String line = Serial.readStringUntil('\n');
    line.trim();
    if (line.length()) {
      char c = line.charAt(0);
      float arg = (line.length() > 1) ? line.substring(1).toFloat() : 0.0f;

      switch (c) {
        case '?': help(); break;
        case 's': scanAll(); break;

        case 'a':
          streamAngle = !streamAngle;
          Serial.printf("angle stream %s\n", streamAngle ? "ON — turn the rotor by hand"
                                                         : "OFF");
          break;

        case 'b': {
          float vb = readVbat();
          Serial.printf("VBAT = %.2f V  (pin 41 raw -> x%.1f)\n", vb, VBAT_DIV_INV);
          if (vb < 1.0f) Serial.println("  ~0 V: divider not fitted, or loop key is OUT. Both are fine on USB-only.");
          else if (vb < 12.0f) Serial.println("  *** BELOW 12 V CUTOFF — charge the pack. ***");
          break;
        }

        case 'e':
          motor.enable();          // sets driver EN high AND the motor's enabled flag
          motorEnabled = true;
          spinStartMs  = millis();
          Serial.printf("M1 ENABLED. voltage_limit = %.2f V (~%.2f A). "
                        "Auto-disable in %lu s.\n",
                        motor.voltage_limit, motor.voltage_limit / PHASE_RES,
                        SPIN_TIMEOUT_MS / 1000UL);
          break;

        case 'd':
          targetVel = 0.0f;
          motor.disable();         // zeroes the phases AND clears the enabled flag
          motorEnabled = false;
          Serial.println("M1 disabled.");
          break;

        case 'u': {
          float v = constrain(arg, 0.0f, OPENLOOP_V_CAP);
          if (arg > OPENLOOP_V_CAP)
            Serial.printf("REFUSED %.2f V — open-loop cap is %.1f V (%.1f A limit / %.2f ohm). "
                          "Clamped.\n", arg, OPENLOOP_V_CAP, I_MAX, PHASE_RES);
          motor.voltage_limit  = v;
          driver.voltage_limit = v;
          Serial.printf("voltage_limit = %.2f V  ->  est. %.2f A at standstill\n",
                        v, v / PHASE_RES);
          break;
        }

        case 'v':
          targetVel = arg;
          spinStartMs = millis();      // restart the spin timer on a new command
          Serial.printf("target velocity = %.2f rad/s\n", targetVel);
          break;

        case 'x': killAll(); break;

        default: Serial.println("? for help"); break;
      }
    }
  }

  // ---- auto-disable: don't cook a stalled winding while you stare at the serial monitor
  if (motorEnabled && fabsf(targetVel) > 0.01f &&
      (millis() - spinStartMs) > SPIN_TIMEOUT_MS) {
    Serial.println("\n*** SPIN TIMEOUT — auto-disabling. 'e' then 'v' to resume. ***");
    killAll();
  }

  // ---- open-loop move (must be called as fast as possible)
  if (motorEnabled) motor.move(targetVel);

  // ---- telemetry, 10 Hz
  if (millis() - lastPrintMs > 100) {
    lastPrintMs = millis();
    sensor.update();                              // independent measurement

    if (streamAngle) {
      Serial.printf("angle %8.3f rad   vel %8.3f rad/s\n",
                    sensor.getAngle(), sensor.getVelocity());
    } else if (motorEnabled) {
      float vMeas = sensor.getVelocity();
      Serial.printf("cmd %6.2f | meas %6.2f rad/s | err %6.2f | U %.2f V | ~%.2f A | VBAT %.1f V\n",
                    targetVel, vMeas, targetVel - vMeas,
                    motor.voltage_limit, motor.voltage_limit / PHASE_RES, readVbat());
    }
  }
}

/* ============================================================================
 *  WHAT "WORKING" LOOKS LIKE
 *
 *  I2C scan .... 0x36 + 0x6B on Wire; 0x36 on Wire1; 0x36 on Wire2.
 *                A missing 0x36 is almost always a swapped SDA/SCL on a
 *                connector you just re-mated, or a dead 3V3 leg.
 *
 *  'a' + hand ... angle sweeps 0 -> 6.283 rad and wraps cleanly. Dropouts or
 *                a frozen value mean the magnet gap is wrong or the bus is noisy.
 *
 *  'e' + 'v 5' .. rotor turns smoothly, quietly, in one direction. 'meas'
 *                converges toward 'cmd'. Motor stays cool to the touch.
 *
 *  FAILURE SIGNATURES
 *    Cogs / stutters / screeches ....... phase order or a bad phase connection.
 *                                        Kill it. Re-check A/B/C continuity.
 *    Turns but 'meas' stays ~0 ......... encoder is alive but not reading the
 *                                        rotor magnet. Mechanical, not electrical.
 *    'meas' has the wrong sign ......... expected. Phase order sets rotation
 *                                        sense; initFOC() will resolve it later.
 *    Motor gets warm fast .............. STOP. You are over-current. Check that
 *                                        voltage_limit really is <= 3 V.
 *    Nothing at all .................... EN wiring (M1 EN is pin 3 now, not 30),
 *                                        or VM/GND at the Mini, or common ground
 *                                        not tied to the star node.
 *
 *  ONLY after all of the above is clean do you move to initFOC() and closed loop,
 *  where voltage_limit goes back up to 14.5 V.
 * ========================================================================= */

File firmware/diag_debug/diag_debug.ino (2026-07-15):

/* ============================================================================
 *  DIAGNOSTIC — SimpleFOC with internal debug output enabled.
 *
 *  Same pins as before (4/5/6/3), no rewiring. This turns on SimpleFOC's own
 *  debug channel so the library prints exactly what it does while configuring
 *  the Teensy timers. driver.init()'s return value is printed explicitly.
 *
 *  >>> COPY THE ENTIRE SERIAL OUTPUT and send it back. <<<
 *  That text is the smoking gun for why no PWM comes out.
 *
 *  Safe: open-loop, 3 V cap. It will try to spin at the end.
 * ========================================================================= */

#include <SimpleFOC.h>

BLDCMotor      motor  = BLDCMotor(7);
BLDCDriver3PWM driver = BLDCDriver3PWM(4, 5, 6, 3);

void setup() {
  Serial.begin(115200);
  delay(1500);                       // give the USB serial time to attach

  SimpleFOCDebug::enable(&Serial);   // <-- library now narrates its init
  Serial.println("=== SimpleFOC debug enabled ===");

  driver.voltage_power_supply = 14.8;
  driver.voltage_limit        = 3.0;
  driver.pwm_frequency        = 25000;

  Serial.print("calling driver.init() ... returned: ");
  int ok = driver.init();
  Serial.println(ok);                // 1 = success, 0 = fail

  motor.linkDriver(&driver);
  motor.voltage_limit  = 3.0;
  motor.velocity_limit = 20.0;
  motor.controller     = MotionControlType::velocity_openloop;

  Serial.println("calling motor.init() ...");
  motor.init();

  motor.enable();
  Serial.println("=== setup done. commanding 5 rad/s ===");
}

void loop() {
  motor.move(5.0);
}

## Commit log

2026-07-15 Initial import: Rev C docs, firmware (bring-up + IMU), sim, CAD
    [2804wEncoder_CAD_01.SLDPRT, 4s1600mAh.SLDPRT, 4s650mAh.SLDPRT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]
2026-07-15 Add first-trial-assembly hero image with fit-up caption; refresh status
2026-07-20 removed old CAD, general orgianization
    [4s1600mAh.SLDPRT, Corner_R2.SLDPRT, Cube_Assembly_06.SLDASM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]
2026-07-23 working on motorhub electronics integration
    [4s650mAh.SLDPRT, Frame 3_02.SLDPRT]
2026-07-23 rev2 electronics integration
    [Corner_R2.SLDPRT, Frame 3_02.SLDPRT]
